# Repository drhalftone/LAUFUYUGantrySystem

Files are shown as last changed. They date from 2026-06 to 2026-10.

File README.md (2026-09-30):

# LAU FUYU Gantry System

Documentation, wiring reference, system diagram, and control software for a **FUYU
FMC4030 dual-X gantry** — two parallel X rails driven in hardware lockstep, with a Y
cross-beam riding between them, controlled from a PC over Ethernet.

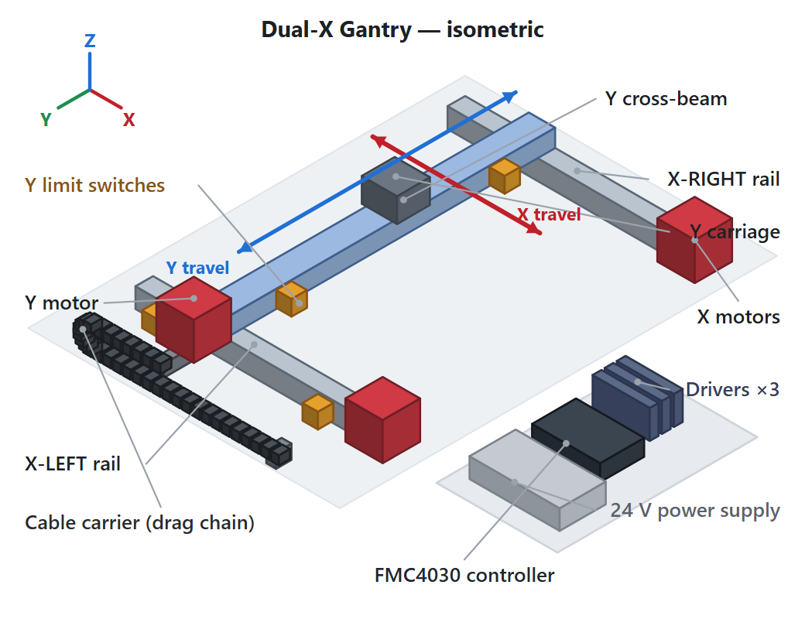
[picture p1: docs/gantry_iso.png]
Isometric diagram of the dual-X gantry


<sub>Isometric view of the system: the two X rails (driven in lockstep), the Y cross-beam
and carriage, the three motors, the photoelectric limit switches, the X-axis cable carrier (drag
chain), and the control cabinet (FMC4030 controller, three drivers, and 24 V supply).
Rendered from [`gantry_iso.svg`](gantry_iso.svg).</sub>

This repository contains three things:

| Path | What it is |
|---|---|
| [`FUYU_FMC4030_Assembly_Wiring_Manual.html`](FUYU_FMC4030_Assembly_Wiring_Manual.html) | Self-contained assembly & wiring manual (open in any browser). The authoritative reference for build, DIP-switch, and terminal-by-terminal wiring detail. |
| [`gantry_iso.svg`](gantry_iso.svg) | Isometric diagram of the mechanical system (embedded in the manual, also usable standalone). |
| [`FuyuRailController/`](FuyuRailController/) | Qt/C++ application that drives the gantry through the FMC4030 motion controller. |

> **Not redistributed here:** vendor-supplied FUYU datasheets, the FMC4030 SDK binaries,
> controller software, and reference archives. Building `FuyuRailController` against real
> hardware needs the FMC4030 SDK DLL from FUYU — see
> [`FuyuRailController/sdk/README.txt`](FuyuRailController/sdk/README.txt).

---

## 1. System overview

This is a **dual-X gantry**. Two parallel rails — **X-Left** and **X-Right** — run in the
same direction and move together; a **Y** cross-beam spans between them and travels along
their length.

The defining design choice is in how the X axis is driven:

- Each of the three motors keeps its **own** stepper driver, but the **two X drivers share
  one controller axis** (axis 1). They receive the *same* pulse and direction signals, so
  the two rails step in **perfect hardware lockstep** and physically cannot drift out of
  sync.
- The Y beam has its own axis (axis 3).
- Because the rails share a pulse source, the gantry **cannot be squared electronically** —
  squareness is set **mechanically at assembly** and held by the rigid beam.

The **FMC4030** is a pulse-type, 3-axis motion controller built around a 32-bit ARM chip.
It generates **pulse (PU)** and **direction (DR)** signals for three external stepper
drivers, reads the axis limit/home switches, provides 4 digital inputs and 4 digital
outputs, and is commanded by a host PC over **Ethernet** (default `192.168.0.30:8088`).

### Axis mapping

| Physical axis | Controller channel | Pulse / Dir / 5 V | Limit inputs |
|---|---|---|---|
| **X-Left** (gantry rail 1) | **Axis 1** (both X drivers share this axis) | `PU1 / DR1 / 5V` | `LP1 / LN1` |
| **X-Right** (gantry rail 2) | **Axis 1** (same terminals, paralleled) | `PU1 / DR1 / 5V` | none fitted |
| **Y** (cross-beam) | Axis 3 | `PU3 / DR3 / 5V` | `LP3 / LN3` |

Axis 2 (`PU2 / DR2`, `LP2 / LN2`) is **unused** — both X drivers are fed from axis 1.
This build uses **four** limit switches: a positive/negative pair on **X-Left** and a
positive/negative pair on **Y**.

---

## 2. Hardware

### 2.1 Bill of materials

| Qty | Item | Model / spec | Role |
|---|---|---|---|
| 1 | Motion controller | **FMC4030** (3-axis) | Pulse/dir generation, limit reading, host comms |
| 3 | Stepper driver | **FMDD50D40NOM** (DC 20–50 V, 1.0–4.0 A/phase) | One each: X-Left, X-Right, Y |
| 3 | Linear module (rail) | **FUYU FSK40** ball-screw module | X-Left, X-Right, and Y beam; carriage-top adapter plate in [`cad/`](cad/) |
| 3 | Stepper motor | **57HS056TF075A-03** (NEMA 23, 2-phase, 1.8°, 2.0 A, ≥ 80 N·cm) | X-Left rail, X-Right rail, Y beam |
| 4 | Limit / home switch | Slot-type photoelectric, **NPN normally-open (NO)**, 5–24 V | +/− pair on X-Left, +/− pair on Y (X-Right has none) |
| 1 | DC power supply | **24 VDC**, sized ≥ 3 × motor current + margin (24 V / 10 A is a safe start) | System power; AC 100–220 V input |
| 1 | Ethernet cable | Standard RJ45 | Host communication (CN3) |
| — | Wiring | Hook-up wire, ferrules, PE ground, AC fuse/breaker | Interconnect |

### 2.2 Component specifications

**Stepper motor — 57HS056TF075A-03**: 2-phase, 1.8° ±5%, 2.0 A/phase, 1.5 VDC, 0.75 Ω,
2.7 mH, holding torque ≥ 80 N·cm, NEMA 23 (57 mm) frame, Ø8 mm shaft, 4-wire (XH-4),
0.7 kg.

**Stepper driver — FMDD50D40NOM**: 2-phase DSP driver, DC 20–50 V input, 1.0–4.0 A/phase
(8 current steps), up to 40000 microsteps/rev, max pulse rate 200 Kpps, **falling-edge
active**, auto idle-current halving after pulses stop > 1.5 s, 118 × 24.3 × 75.5 mm.

**Limit / home switch**: slot-type photoelectric, 5–24 V, **NPN normally-open, low-level
active** (required by the FMC4030). Doubles as the **home/origin reference** for each axis.

**Controller — FMC4030**: 24 VDC power (VN+/VN−); 3 × 5 V pulse + direction outputs; 6
limit inputs (LP/LN × 3, 24 V NPN-NO); 4 digital inputs (24 V, low-active) and 4 digital
outputs (24 V open-drain, ≤ 300 mA); Ethernet (CN3), RS-232 DB9 (CN1), RS-232/485 RJ45
(CN2); default IP `192.168.0.30`, port `8088`.

### 2.3 Driver DIP-switch setup

Set the 8 DIP switches on **each** FMDD50D40NOM driver *before* wiring power.

- **SW4 = OFF** — selects pulse/subdivision mode. **Required.** `SW4 = ON` puts the driver
  in I/O mode and it will ignore the FMC4030's pulses.
- **Output current (SW1–SW3) → 2.0 A** to match the motor: `SW1 = OFF · SW2 = OFF · SW3 = ON`.
- **Microstepping (SW5–SW8) → 1600 steps/rev** (recommended start):
  `SW5 = OFF · SW6 = OFF · SW7 = ON · SW8 = ON`.

Use the **same** microstep value on all three drivers and record it — distance/speed math
depends on steps-per-rev.

### 2.4 Wiring summary

Full, terminal-by-terminal wiring (with diagrams and the complete terminal reference) is in
the **HTML manual**, §7–§12. Summary:

**Power (§7):** build a 24 V bus from the supply; feed the controller (VN+/VN−), all three
drivers (V+/V−), and the limit switches from it. Mains (100–220 VAC) goes only to the
supply's L / N / earth.

**Motor → driver (§8)** — 57HS XH-4 colours map straight to coils. Coil pairing is what
matters: **A = Black + Green, B = Red + Blue**.

| Motor pin | Colour | Coil | Driver |
|---|---|---|---|
| 1 | Black | A+ | `A+` |
| 2 | Green | A− | `A−` |
| 3 | Red | B+ | `B+` |
| 4 | Blue | B− | `B−` |

Both X motors are mounted the **same way** and wired with the **same** colour map (no
`A+/A−` swap) so the shared rotation moves both carriages the same direction. X direction
is fixed **in wiring** (it can't be inverted in software because the rails share one axis);
Y direction can be inverted in wiring *or* software.

**Driver → controller (§9)** — **common-anode**: the controller's 5 V drives each driver's
`PU+`/`DR+` (tied together); the controller's `PUx`/`DRx` pins sink into `PU−`/`DR−`. The
**two X drivers are paralleled onto axis 1** (`5V`, `PU1`, `DR1`); the Y driver uses axis 3
(`5V`, `PU3`, `DR3`). Leave `MF+/MF−` open (holding torque on). Use the **5 V** rail for
`PU+/DR+`, never 24 V.

**Limit switches (§10)** — each switch: **Brown → 24 V+, Blue → 0 V, Black → signal**.
Positive-end switch black wire → `LP`, negative-end → `LN`. X gantry pair → `LP1 / LN1`
(axis 1); Y pair → `LP3 / LN3`. Switches **must be NPN normally-open** (inputs are
low-level active).

**Digital I/O & comms (§11):** 4 inputs `IN0–IN3` (24 V active-low); 4 open-drain outputs
`OP1–OP4` (sink ≤ 300 mA, wire load between 24 V+ and the output). Host link is Ethernet on
**CN3**; set the PC adapter to the controller's subnet (e.g. `192.168.0.35 / 255.255.255.0`)
and verify with `ping 192.168.0.30`.

### 2.5 Mechanical & safety notes

- **Square the gantry mechanically:** set the two X rails truly parallel and equal-length,
  mount the Y beam perpendicular (equal diagonals), and start both X carriages at the same
  position before fixing the beam. The controller can't correct rail-to-rail squareness.
- **Mount both X motors identically** (same orientation, same end) so shared rotation =
  same travel. The §14 jog test confirms it: nudge axis 1 — both rails should move together.
- Position the **negative-end** switch at the home/zero end and the **positive-end** switch
  at the far end of each axis, with margin before the hard stop. X-Right has no over-travel
  switch, so set conservative soft-travel limits in software.
- Keep ≥ 50 mm between side-by-side drivers (thermal shutdown at 80 °C); keep AC mains wiring
  separated from low-voltage signal/Ethernet wiring.
- ⚠ **The supply primary side carries 100–220 VAC.** Wire everything de-energized with the
  AC plug removed; bond the controller `PE` and frame to protective earth; don't plug/unplug
  a motor while its driver is powered.

---

## 3. Software — `FuyuRailController`

A small **Qt Widgets** application for driving the FMC4030. Its defining choice: it
**reuses the Velmex widget classes** from `LAU3DVideoRecorder` *verbatim* and only **swaps
the controller** — `LAUVelmexController` is reimplemented to talk to the FMC4030 over
Ethernet instead of a serial Velmex VXM. You get the proven Velmex control panel driven by
FUYU hardware.

### 3.1 Build & run

Verified to build clean with **Qt 6.9.3, MSVC 2022 (64-bit)**.

**Simulation (default — no hardware or SDK needed):**

```sh
qmake
nmake            # Windows/MSVC   (or make / jom)
./FuyuRailController
```

A built-in simulator eases each axis toward its commanded target and emulates the limit
switches, so the entire UI is exercisable with nothing plugged in. In Qt Creator: open
`FuyuRailController.pro`, pick the Qt 6 / MSVC 2022 kit, Build & Run.

**Real hardware:**

```sh
qmake CONFIG+=hardware
nmake
```

The vendor library is loaded **at run time** via `QLibrary`, so the build needs **no `.lib`
and no `.h`** — and it launches even with no SDK present (reporting *disconnected*). Place
`FMC4030-Dll.dll` (Windows, 64-bit) next to the `.exe` or on `PATH`, or `libFMC4030-Lib.so`
on the Linux library path; bitness must match the build. The `.pro` auto-copies
`sdk/FMC4030-Dll.dll` next to the built executable on Windows.

The controller defaults to **`192.168.0.30:8088`**; put your PC adapter on the same subnet.

### 3.2 Axis mapping in software

The FMC4030 SDK numbers axes `0 = X (PU1)`, `1 = Y (PU2)`, `2 = Z (PU3)`. On this gantry the
shared-X / separate-Y layout maps as:

| App axis | SDK index | Physical |
|---|---|---|
| X gantry | 0 | both X rails (shared signal) |
| (unused) | 1 | — |
| Y beam | 2 | cross-beam carriage |

`main.cpp` builds the panel with `LAUMultiVelmexWidget({0, 2})` — one checkable group box
per axis, each with Left-Limit / Slider-Position / Right-Limit rows and Calibrate / Center /
Scan buttons, plus a `?` settings dialog.

### 3.3 How it works

- **Units:** the widgets speak integer "counts"; here **1 count = 1 µm** (0.001 mm). The
  controller converts counts ↔ millimetres at the SDK boundary; the display shows **mm**
  (default) or **inches**, switchable in the `?` dialog (the **Speed** field follows the
  unit). The unit choice is shared by all axes.
- **Motion is non-blocking.** A move issues `FMC4030_Jog_Single_Axis` once; a 500 ms timer
  polls `FMC4030_Check_Axis_Is_Stop` until the axis settles, so position stays live and a
  Stop can be processed mid-move. The position slider is a *setpoint* (Center/Scan jump
  straight to it).
- **Calibration discovers travel from the limit switches**, like Velmex: `calibrateLeft()`
  homes the negative switch (sets zero); `calibrateRight()` seeks the positive switch (sets
  travel, bounded to a 2000 mm safety ceiling if a switch is missing). The slider range then
  reflects real travel.
- **Settings dialog (`?`):** Units · Home Toward · Speed · Scan Steps. The Velmex-specific
  mechanical fields were removed because the FMC4030 abstracts them away.

### 3.4 Blocking vs non-blocking SDK (important)

FUYU ships **two** builds of the DLL — *blocking* and *non-blocking* — with identical
function names but different behaviour. **This project requires the non-blocking X64 build**,
because the controller is poll-based (one jog, then poll is-stopped). With the blocking DLL,
a motion call doesn't return until the move finishes — you lose live position feedback and
the ability to abort mid-move, which is a safety concern on a gantry. See
[`FuyuRailController/sdk/README.txt`](FuyuRailController/sdk/README.txt).

### 3.5 Source layout

| File | Purpose |
|---|---|
| `lauvelmexwidget.h` / `.cpp` | Velmex widget classes (verbatim) **+** the FMC4030-backed `LAUVelmexController` and trimmed `LAUVelmexSettingsDialog` |
| `main.cpp` | Builds `LAUMultiVelmexWidget({0, 2})` |
| `FuyuRailController.pro` | qmake project; selects simulation vs hardware |
| `sdk/` | Holds the non-blocking X64 `FMC4030-Dll.dll` (not committed) + `README.txt` |

---

## 4. Repository layout

```
.
├── FUYU_FMC4030_Assembly_Wiring_Manual.html   # assembly & wiring manual
├── gantry_iso.svg                             # isometric system diagram
├── README.md                                  # this file
└── FuyuRailController/                         # Qt/C++ controller app
    ├── FuyuRailController.pro
    ├── main.cpp
    ├── lauvelmexwidget.h / .cpp
    └── sdk/README.txt
```

---

## 5. Credits & license

© 2026 Dr. Daniel L. Lau. The control application reuses the `LAU3DVideoRecorder` Velmex
module. FUYU, FMC4030, and the component model numbers are trademarks/products of their
respective owners; their proprietary datasheets and SDK binaries are not redistributed here.

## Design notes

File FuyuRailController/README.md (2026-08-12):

# FuyuRailController

A small Qt Widgets application for driving the **FUYU FMC4030** three-axis motion
controller that runs the dual-X gantry (two X rails + a Y cross-beam).

Its defining design choice: it **reuses the Velmex widget classes** from
`LAU3DVideoRecorder` *verbatim* and only **swaps the controller**. The Velmex GUI
(`LAUVelmexWidget`, `LAUMultiVelmexWidget`, `LAUVelmexSettingsDialog`, `LAUDoubleSpinBox`)
is unchanged; `LAUVelmexController` is reimplemented to talk to the FMC4030 over Ethernet
instead of a serial VXM. So you get the proven Velmex control panel, driven by FUYU hardware.

---

## Quick start (simulation — no hardware or SDK needed)

The default build runs against a built-in **software simulator**, so it compiles and runs
with nothing plugged in.

**Qt Creator:** open `FuyuRailController.pro`, select the Qt 6 / MSVC 2022 kit, and Build &
Run.

**Command line:**
```
qmake
nmake            # (Windows/MSVC)   or  make / jom
./FuyuRailController
```

Verified to build clean with **Qt 6.9.3, MSVC 2022 (64-bit)**.

You'll see one checkable group box per axis ("X gantry Controls:", "Y beam Controls:"),
each with Left-Limit / Slider-Position / Right-Limit rows and Calibrate / Center / Scan
buttons, plus a `?` settings dialog. In simulation each axis eases toward its commanded
target and the limit switches are emulated, so you can exercise the whole UI.

## Building for real hardware

The vendor library is loaded **at run time** (via `QLibrary`), so the build needs **no
`.lib` and no `.h`** — only the DLL at run time, and only if you actually have hardware.

1. Build with the `hardware` config:
   ```
   qmake CONFIG+=hardware
   nmake
   ```
   In Qt Creator: **Projects ▸ Build ▸ qmake ▸ Additional arguments → `CONFIG+=hardware`**.
   (This build links and runs even with **no** SDK present — it just reports *disconnected*.)
2. For real hardware, place the runtime library where it can be found:
   - Windows: **`FMC4030-Dll.dll`** next to the built `.exe` (or on the `PATH`)
   - Linux: **`libFMC4030-Lib.so`** on the library path
3. **Bitness must match** (use the 64-bit DLL with the MSVC 64-bit kit). On startup the app
   resolves the SDK symbols; if the DLL is missing or a symbol is absent it logs a warning
   and runs disconnected.

A copy of the DLL already lives in `sdk/` and is auto-copied next to the built `.exe` by the
`.pro` (win32 post-link step), so a hardware build finds it with no manual copying.

### Blocking vs non-blocking SDK (important)

FUYU ships **two** builds of the DLL — *blocking* and *non-blocking* — with identical function
names but different behaviour. **This project uses the non-blocking X64 build** (`sdk/FMC4030-Dll.dll`,
extracted from `国外FMC4030/FMC4030 API file (non blocking).rar`).

It must stay non-blocking, because `LAUVelmexController` is **poll-based**: it issues one
`FMC4030_Jog_Single_Axis` and then polls `FMC4030_Check_Axis_Is_Stop` from a 500 ms timer.

| | Non-blocking (used) | Blocking (do **not** use) |
|---|---|---|
| motion call returns | immediately | only when the move finishes |
| live position during a move | yes — the poll updates it | no — jumps at the end |
| Stop / abort mid-move | works | can't be processed until the move ends |
| controller thread during a move | responsive | frozen inside the call |

With the blocking build the code still *compiles and connects*, and simple point-to-point moves
complete — so it can look fine in casual testing — but you lose live position feedback and the
ability to abort a move, which is a safety concern on a gantry. If you ever re-extract the DLL,
take it from the **"non blocking"** archive (X64 subfolder). See `sdk/README.txt` for the path.

### Network setup

The controller defaults to `192.168.0.30:8088`. Set the PC adapter that's cabled to it to a
static address on the **same subnet** — e.g. `192.168.0.35 / 255.255.255.0` — and leave the
**default gateway blank**: the controller sits on an isolated segment, and a gateway here
would compete with the default route of whatever adapter carries your internet.

**1. Find the right adapter.** The FMC4030 is a 10/100 device, so its port shows up at
100 Mbps:

```powershell
Get-NetAdapter | Select-Object Name,ifIndex,Status,LinkSpeed
Get-NetIPConfiguration | Select-Object InterfaceAlias,IPv4Address,IPv4DefaultGateway
```

An address of **`169.254.x.x`** on that port is the classic symptom: DHCP is on (or is off with
no static address set), nothing answered, and Windows self-assigned an APIPA address. It cannot
reach `192.168.0.0/24` in that state.

**2. Set the static address** (needs an elevated prompt; substitute your adapter name):

```powershell
netsh interface ip set address name="Ethernet 2" static 192.168.0.35 255.255.255.0
```

**3. Verify** — both checks should pass before launching the app:

```powershell
ping 192.168.0.30
Test-NetConnection -ComputerName 192.168.0.30 -Port 8088   # TcpTestSucceeded : True
```

`TcpTestSucceeded` is the one that matters — it proves the SDK's port is open. Note that
`Test-NetConnection` may report `PingSucceeded : False` even when plain `ping` gets replies;
that's its own ICMP path being filtered, not a controller fault.

To undo, put the adapter back on DHCP: `netsh interface ip set address name="Ethernet 2" dhcp`.

The app **remembers the last IP/port** in `QSettings`, so the `192.168.0.30` default only
applies on a first run — if a stale address was saved, correct it in the `?` dialog.

---

## Axis mapping

The FMC4030 SDK numbers axes `0 = X (PU1)`, `1 = Y (PU2)`, `2 = Z (PU3)`. On this gantry both
X rails share **one** controller axis (a single PU/DR signal), so:

| App axis | SDK index | Physical |
|---|---|---|
| X gantry | 0 | both X rails (shared signal) |
| (unused) | 1 | — |
| Y beam | 2 | cross-beam carriage |

`main.cpp` creates the panel with `LAUMultiVelmexWidget({0, 2})`.

## How it works

- **Units:** the widgets speak integer "counts"; here **1 count = 1 µm** (0.001 mm). The
  controller converts counts ↔ millimetres at the SDK boundary, and the display can show
  **mm** (default) or **inches** — switchable in the `?` dialog, where the **Speed** field
  also follows the unit (mm/s ↔ in/s). The unit choice is shared by every axis.
- **Motion is non-blocking.** A move issues `FMC4030_Jog_Single_Axis` once; the controller's
  500 ms `timerEvent` polls `FMC4030_Check_Axis_Is_Stop` until the axis settles. The position
  slider is a *setpoint* (Center/Scan jump straight to it — no scrolling). This depends on the
  **non-blocking** SDK build (see *Blocking vs non-blocking SDK* above).
- **Calibration discovers travel from the limit switches**, like Velmex: `calibrateLeft()`
  homes the **negative** switch (sets zero) and `calibrateRight()` seeks the **positive**
  switch (sets the travel). The sliders' range then reflects the real travel — there is no
  manual "full travel" field.
- **Settings dialog** (`?`): **Units · Home Toward · Speed · Scan Steps**. The Velmex-specific
  mechanical fields (rotary, motor clicks/rotation, travel/rotation) were removed because the
  FMC4030 abstracts them away.

## Files

| File | Purpose |
|---|---|
| `lauvelmexwidget.h/.cpp` | Velmex widget classes (verbatim) **+** the FMC4030-backed `LAUVelmexController` and trimmed `LAUVelmexSettingsDialog` |
| `main.cpp` | Builds `LAUMultiVelmexWidget({0, 2})` |
| `FuyuRailController.pro` | qmake project; selects simulation vs hardware |
| `sdk/` | holds the **non-blocking X64** `FMC4030-Dll.dll` (auto-copied next to the `.exe`); see `sdk/README.txt` |

## FMC4030 vs Velmex (short version)

The Velmex VXM is an RS-232 controller you drive with ASCII commands in motor **step counts**,
with **blocking** moves (poll busy/ready). The FMC4030 is an **Ethernet** controller driven by
a C **SDK** in native **millimetres**, with **non-blocking** moves (poll is-stopped) and
hardware multi-axis interpolation. We kept `LAUVelmexController`'s public interface identical
and replaced only its internals (serial+steps → SDK+mm), so the GUI didn't change.

## Things to verify on the bench

- `calibrateRight` relies on the FMC4030 **halting the axis at the positive limit switch**
  (bounded to a 2000 mm safety ceiling if a switch is missing). Confirm the controller stops
  at `LP` before trusting auto-travel.
- Homing is assumed to **zero the axis at the switch** — standard for the FMC4030 but confirm.
- `FMC4030_Set_Output` polarity follows the SDK wording (status `0` = output HIGH); flip in the
  controller if your wiring is inverted.

---

© 2026 Dr. Daniel L. Lau. Reuses the LAU3DVideoRecorder Velmex module.

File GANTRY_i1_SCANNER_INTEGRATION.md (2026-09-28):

# Replacing the i1 iSis with a FUYU Gantry + i1Pro — Integration Design

**Status:** design sketch only (no code yet).
**Goal:** retire the sealed **i1 iSis** chart scanner and rebuild the same
chart-measurement workflow from two off-the-shelf pieces we already control:

- the **FUYU FMC4030 dual-X gantry** (`FUYUAutomation/FuyuRailController`) for **motion**, and
- the **X-Rite i1Pro** spectrophotometer (`LAUXRiteController`, SDK 4.2.9) for **measurement**.

The iSis combines motion and measurement in one box. We split those: the gantry
positions the i1Pro over each patch, and a thin orchestrator triggers a spot
measurement at every stop. Everything downstream of acquisition is reused
unchanged.

---

## 1. Why this is mostly glue, not a rewrite

### 1.1 The data structures already match

The i1Pro SDK and the iSis SDK share identical measurement primitives:

| Quantity | iSis | i1Pro |
|---|---|---|
| Spectral bands | `SPECTRUM_SIZE == 36` (380–730 nm @ 10 nm) | same |
| Tristimulus | `TRISTIMULUS_SIZE == 3` | same |
| Density | `DENSITY_SIZE == 4` | same |
| Trigger | `ISIS_TriggerMeasurement(...)` | `I1_TriggerMeasurement(dev)` |
| Read back | `ISIS_GetSpectrum/GetTriStimulus/GetDensities(buf, row, col)` | `I1_GetSpectrum/GetTriStimulus/GetDensities(dev, buf, index)` |

Because the shapes are identical, **`LAUi1IsisDialog::ColorMeasurement` is reused
verbatim**, and so are:

- `generateTestPattern()` — TIFF chart rendering,
- `saveMeasurementsToDisk()` / `readMeasurementsFromDisk()` — CSV,
- `exportToI1ProfilerCGATS()` and `exportToCxF3()`,
- `mergeMeasurementLists()`, `writeTI3File()`, and the Argyll `targen`/`colprof` flow.

We replace **only** the acquisition path (`scanTarget()`), not the data model or
the outputs.

### 1.2 The gantry already exposes the exact hook we need

`LAUMultiVelmexWidget::scanUserPath(QList<QVector4D> points)` accepts an arbitrary
list of coordinates, rasters through them non-blocking, and emits

```
emitTriggerScanner(float pos, int n, int N)   // n = current point, N = total
```

**at each point.** That signal is precisely where the i1Pro measurement fires. We
do not have to write the motion loop — it exists and is already poll-settled
(`FMC4030_Jog_Single_Axis` then poll `FMC4030_Check_Axis_Is_Stop` on a 500 ms
timer). The gantry is built with axes `{0, 2}` = **X gantry + Y beam**, which is
the 2-D plane we need.

### 1.3 The i1Pro measurement logic already exists

`LAUEyeOneDialog` (in `LAUXRiteController`) already wraps the i1Pro lifecycle:
`I1_GetDevices` → `I1_OpenDevice` → mode select (`I1_REFLECTANCE_SPOT`) →
`I1_Calibrate` → `I1_TriggerMeasurement` → `I1_GetSpectrum`. That code refactors
directly into a reusable, headless **measurement helper** (no dialog UI required).

---

## 2. The conceptual mapping

| iSis (today) | Gantry + i1Pro (proposed) |
|---|---|
| `scanTarget()` sets chart geometry in mm, waits for chart insert, pre-scans to register | Jog to two corners to register the chart, generate an XY path from the patch grid, hand it to `scanUserPath()` |
| `ISIS_TriggerMeasurement(false)` — 2 rows per trigger | `emitTriggerScanner` callback → one `I1_TriggerMeasurement` per patch |
| `ISIS_GetTriStimulus/Spectrum/Densities(row, col)` | `I1_Get*(device, buf, 0)` into the same `ColorMeasurement` |
| optical auto-registration via the alignment bar | **two-corner manual jog** (see §4) |
| device finds patches itself | host computes patch centres → gantry XY (mm) |

---

## 3. Proposed architecture

Recommended: a **new combined dialog**, e.g. `LAUGantryScannerDialog`, that leaves
the existing iSis path untouched and owns three collaborators:

```
LAUGantryScannerDialog
├── motion:       LAUMultiVelmexWidget({0, 2})      // reused from FuyuRailController
│                 (or just its LAUVelmexController)
├── measurement:  LAUi1ProMeasurer                  // headless helper refactored
│                 (open / calibrate / measure)       //   out of LAUEyeOneDialog
└── data + I/O:   LAUi1IsisDialog::ColorMeasurement  // reused verbatim,
                  + generateTestPattern / exporters  //   incl. all exports
```

The scan loop **replaces** `scanTarget()`:

```
1. Operator registers the chart (two-corner jog, §4).
2. Build QList<QVector4D> path = patchCentresToXY(grid, corners)   // §4.3
3. controller->scanUserPath(path)
4. On each emitTriggerScanner(pos, n, N):
     - confirm axes stopped + dwell (§5.2)
     - measurer.trigger(); measurer.readInto(measurement[n])
     - measurement[n].row/col = gridIndexOf(n)
     - append to scanMeasurements
5. On completion: hand scanMeasurements to the existing exporters.
```

Alternative structures considered (not recommended for the first cut):

- **Swap inside `LAUi1IsisDialog::scanTarget()`** — least new UI, but deletes the
  iSis option and entangles two device stacks in one method.
- **Merge the repos** — pull the Velmex classes into `LAUXRiteController`. Worth
  doing eventually so it is one app/one build, but it is a packaging decision that
  can follow a working prototype.

> Either way the two repos must be brought into one build. The Velmex classes
> (`lauvelmexwidget.h/.cpp`) and the i1Pro SDK linkage (`i1Pro64.lib`, runtime
> `FMC4030-Dll.dll`) both end up in the same `.pro`.

---

## 4. Registration — the two-corner jog

The gantry has no idea where the printed chart sits on its bed; unlike the iSis it
cannot find the chart optically. So the operator **jogs the i1Pro head to two
diagonally-opposite patch centres** and we derive the patch→XY map from those.

### 4.1 Procedure

1. Place and fix the chart on the bed (a registration corner/fence helps
   repeatability but is not required).
2. Calibrate the i1Pro on its white tile (§5.1).
3. Jog the head until the aperture is centred on patch **(row 0, col 0)** →
   record gantry position **P₀ = (x₀, y₀)** in mm.
4. Jog to the opposite corner patch **(row R−1, col C−1)** (for the default chart,
   row 29, col 28) → record **P₁ = (x₁, y₁)**.
5. Store P₀, P₁ for the run (and persist to `QSettings` for repeat runs on the
   same fixture).

The jog UI already exists: the Velmex position sliders / spin boxes move a single
axis to a setpoint. A small "Set corner 1 / Set corner 2" pair of buttons captures
the current `position(0)` / `position(2)` of each axis.

### 4.2 What two corners give you (and what they do not)

Two diagonally-opposite patch centres pin down **translation + independent
per-axis scale** under the assumption that the chart's rows/cols are
**axis-aligned** with the gantry (no in-plane rotation or skew):

```
colPitchX = (x₁ − x₀) / (C − 1)      // mm of X per column step
rowPitchY = (y₁ − y₀) / (R − 1)      // mm of Y per row step
originXY  = P₀                        // centre of patch (0,0)
```

This absorbs print scaling and bed placement automatically — we do **not**
hard-code the 6 mm patch pitch; we measure it from the two corners. (The iSis
artwork is ~6 mm patches over a 204 mm sheet, a useful sanity check: expect
`colPitchX ≈ rowPitchY ≈ 6 mm`.)

**Limitation:** two diagonal points cannot separate rotation from scale (3 unknowns,
2 equations). If the chart is slightly **rotated** on the bed, a diagonal pair
silently folds that rotation into the pitches and mis-targets interior patches.

Two robust options, both still "two corners":

- **Same-edge pair (handles rotation):** jog to **(0,0)** and **(0, C−1)** — both on
  the top row. Their difference is the pure **column axis vector** `u`, which gives
  column pitch **and** the chart's rotation angle. Take the row axis `v` ⟂ `u`
  (perpendicular), with row pitch from the artwork or a quick third tap. Best when
  the bed fixture cannot guarantee alignment.
- **Diagonal pair (simplest):** jog to **(0,0)** and **(R−1, C−1)**, assume
  axis-aligned. Fine when a fence/corner squares the chart to the gantry travel.

Recommendation: **diagonal pair + a mechanical fence** for the first build (assume
no rotation); upgrade to the same-edge pair (or a third corner → full affine) only
if bench tests show interior-patch drift.

### 4.3 Patch → XY (axis-aligned, diagonal corners)

```cpp
// grid index n (raster order) → patch (row, col) → gantry XY in mm
int row = n / C;
int col = n % C;
double x = originX + col * colPitchX;     // colPitchX = (x1-x0)/(C-1)
double y = originY + row * rowPitchY;     // rowPitchY = (y1-y0)/(R-1)
path << QVector4D(x, 0.0f, y, 0.0f);      // dim 0 = X, dim 2 = Y (Z,W unused)
```

`scanUserPath()` already clamps each coordinate to the calibrated axis travel, so a
bad corner capture cannot drive the head past a soft limit.

> **Full-affine upgrade (optional):** capturing a **third** corner (e.g. (R−1, 0))
> lets you solve a general 2-D affine map `XY = A·[col,row] + b` (handles rotation
> **and** skew). Same UI, one more "Set corner 3" tap. Worth keeping the math
> general so this is a config flag, not a rewrite.

---

## 5. Engineering concerns (the parts that are not glue)

### 5.1 No Z axis — fixed standoff
The gantry is X/Y only (`{0, 2}`); there is no Z. The i1Pro is a **contact spot**
instrument whose aperture wants to sit on the media. So the head mounts to the Y
carriage at a **fixed Z**, and reflectance accuracy depends on the media being
**flat and at a known height**. This is the largest physical risk. Mitigations:
spring-loaded/compliant head mount, a vacuum or platen to hold media flat,
verification against a known reference chart. (If standoff proves critical, a
future Z stage on the unused FMC4030 axis 1 is an option — but that axis currently
carries the shared X signal, so it would need rewiring.)

### 5.2 Settling dwell
Motion is non-blocking and "settled" means `FMC4030_Check_Axis_Is_Stop` returned
stopped. Add a short **dwell** (e.g. 200–500 ms, tunable) after stop and before
`I1_TriggerMeasurement` so carriage vibration does not smear the reading.

### 5.3 Calibration & expiry
The i1Pro must be **calibrated on its white tile** before a run, and calibration
expires (`I1_TIME_SINCE_LAST_CALIBRATION` is −1 / aged). Two patterns:

- **Manual:** operator calibrates by hand (head on tile) before the run, like
  `LAUEyeOneDialog::onCalibrateButtonClicked()`.
- **Automated:** mount the white tile at a **known XY** on the bed; the scan loop
  parks there and calls `I1_Calibrate()` at the start (and optionally every N
  patches if a long run risks expiry).

### 5.4 Throughput
~870 patches × (move + dwell + ~1–2 s measurement) ≈ **15–30 min** per chart,
versus seconds for the iSis. Acceptable, but set expectations and show a progress
dialog (the iSis path already used `QProgressDialog`).

### 5.5 Threading
`LAUVelmexController` lives in its own `QThread` and polls on a 500 ms timer. The
i1Pro SDK calls must be serialized against motion. Cleanest first cut: drive the
measurement from the **GUI thread** inside the `emitTriggerScanner` slot
(`Qt::QueuedConnection`), only after motion confirms stopped — no shared-state race
with the controller thread.

### 5.6 M0 / M1 / M2 (UV handling)
The iSis exposed an illumination mode (UV / No-UV). The i1Pro2 supports M0/M1/M2 via
`I1_RESULT_INDEX_KEY` on a dual measurement (subject to device variant — UV-cut
units expose only M2). Map the old UV toggle onto the i1Pro result index where the
hardware allows; otherwise drop to a single mode and note it in the export header
(`MEASUREMENT_MODE`).

### 5.7 Registration drift over a run
Thermal/mechanical drift over a 20-minute run can shift the origin. If bench tests
show it, re-tap a corner mid-run or add fiducials. Out of scope for v1.

---

## 6. File / change checklist (no code yet)

| Item | Action |
|---|---|
| `lauvelmexwidget.h/.cpp` | **Reuse** as the motion layer (verbatim from `FuyuRailController`). |
| i1Pro measurement helper | **New** `LAUi1ProMeasurer` — refactor open/calibrate/measure out of `LAUEyeOneDialog` (no UI). |
| `LAUGantryScannerDialog` | **New** orchestrator: registration UI (two-corner jog), path build, scan loop, progress. |
| `ColorMeasurement` + exporters | **Reuse** from `LAUi1IsisDialog` (CSV / CGATS / CxF3 / TIFF / Argyll). Consider lifting them into a shared header so the new dialog does not depend on the iSis dialog. |
| `patchCentresToXY()` | **New** small geometry function (§4.3); keep it affine-general so 2- or 3-corner is a flag. |
| Build (`.pro`) | **Merge** Velmex sources + i1Pro SDK link (`i1Pro64.lib`) + runtime `FMC4030-Dll.dll` copy step into one project. Keep the FMC4030 **non-blocking** DLL (poll-based control depends on it). |
| `main.cpp` | Add an entry path that launches `LAUGantryScannerDialog` (alongside, or instead of, the iSis dialog). |

---

## 7. Open questions to resolve before implementation

1. **Head mount & standoff:** how is the i1Pro fixtured to the Y carriage, and how
   is flat media / fixed height guaranteed? (Drives §5.1 — the main risk.)
2. **Calibration tile:** manual pre-run, or mounted at a known XY for automated
   calibration? (§5.3)
3. **Chart squareness:** is there a fence/corner to square the chart to gantry
   travel? Decides diagonal-pair vs same-edge-pair vs full-affine registration (§4).
4. **UV/OBA need:** is M1/M2 required, or is single-mode M0 acceptable? (§5.6)
5. **Packaging:** one merged app, or keep `FuyuRailController` and
   `LAUXRiteController` separate and share code via a small static lib?

---

© 2026 Dr. Daniel L. Lau. Design note; references `LAUXRiteController`
(i1 iSis / i1Pro controller) and `FUYUAutomation/FuyuRailController` (FMC4030 gantry).

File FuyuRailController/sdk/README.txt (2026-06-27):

FMC4030 SDK -- runtime DLL loading
==================================

The app loads the FMC4030 vendor library at RUN TIME (via QLibrary), so the build needs
no .lib and no .h, and has no link-time dependency on the SDK.  A "hardware" build even
launches when the DLL is absent -- it just reports "disconnected".

CURRENT DLL: FMC4030-Dll.dll is the NON-BLOCKING, 64-bit (X64) build, extracted from:
    ../../国外FMC4030/FMC4030 API file (non blocking).rar
        -> FMC4030二次开发库文件（非阻塞）/FMC4030-DLL-X64-20240920/FMC4030-Dll.dll

The non-blocking build is REQUIRED: LAUVelmexController issues one motion command and then
polls FMC4030_Check_Axis_Is_Stop from a 500 ms timer.  With the *blocking* build the motion
call would not return until the move finished, freezing the controller thread (no live
position, and Stop/abort could not be processed mid-move).  Do not swap in the blocking DLL.

This file is auto-copied next to the built .exe by the .pro (win32 post-link step).  For a
manual deploy, place FMC4030-Dll.dll next to FuyuRailController.exe (or on the PATH).

Bitness must match the build (use this 64-bit DLL with the 64-bit MSVC kit).  The app
resolves these symbols at startup:
    FMC4030_Open_Device, FMC4030_Close_Device, FMC4030_Jog_Single_Axis,
    FMC4030_Check_Axis_Is_Stop, FMC4030_Home_Single_Axis, FMC4030_Stop_Single_Axis,
    FMC4030_Get_Axis_Current_Pos
If any is missing it logs a warning and runs disconnected.

NOTE: the simulation build needs none of these files.

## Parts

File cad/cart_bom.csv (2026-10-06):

Unit | Section | Part | Qty | Description | Unit $ | Ext $
Bench box | Frame | 1010 | 2 | Top front/back rail, 24 in | 10.8 | 21.6
Bench box | Frame | 1010 | 2 | Top side rail, 22 in | 9.9 | 19.8
Bench box | Frame | 1010 | 4 | Shelf rail, 20 in | 9.0 | 36.0
Bench box | Frame | 1010 | 1 | Camera mast, 45.71 in | 20.57 | 20.57
Bench box | Frame | 1010 | 1 | Camera boom, 13 in | 5.85 | 5.85
Bench box | Frame | 1010-cut | 10 | 1010 cut charge, per cut | 3.0 | 30.0
Bench box | Frame | 2020 | 4 | Post, 4.71 in | 5.32 | 21.29
Bench box | Frame | 2020-cut | 4 | 2020 cut charge, per cut | 3.18 | 12.72
Bench box | Joining | 4132 | 26 | 10 series 2-hole gusseted inside corner bracket | 7.11 | 184.86
Bench box | Joining | 3416 | 52 | Bolt assembly: 1/4-20 x .375 BHSCS + economy T-nut, 2 per 4132 | 0.71 | 36.92
Bench box | Surfaces | 2637 | 1 | Shelf panel (notch the 4 post corners 2 x 2 in), 24 x 24 in, Lite ACM .236 black | 55.32 | 55.32
Bench box | Surfaces | 2637-cut | 1 | Panel cut-to-size charge, per panel | 16.13 | 16.13
Bench box | Surfaces | 3321 | 4 | Bolt assembly: 1/4-20 x .5 FBHSCS + economy T-nut, panel to rail (countersink the panel) | 0.87 | 3.48
Bench box | Camera | ballhead | 1 | 1/4-20 mini ball head for the camera (est.) | 15.0 | 15.0
Bench box | Camera | 3393-cam | 1 | 1/4-20 stud + economy T-nut, ball head to boom (est.) | 0.73 | 0.73
Bench box | Finish | 2015 | 4 | 10 series 1 x 1 end cap (exposed 1010 ends) | 2.02 | 8.08
Wheeled cart | Frame | 1010 | 2 | Top front/back rail (cantilevers to laptop table), 38 in | 17.1 | 34.2
Wheeled cart | Frame | 1010 | 3 | Top side + laptop end rail, 22 in | 9.9 | 29.7
Wheeled cart | Frame | 1010 | 4 | Lower ring rail, 20 in | 9.0 | 36.0
Wheeled cart | Frame | 1010-cut | 9 | 1010 cut charge, per cut | 3.0 | 27.0
Wheeled cart | Frame | 2020 | 4 | Leg, 16.07 in | 18.16 | 72.64
Wheeled cart | Frame | 2020-cut | 4 | 2020 cut charge, per cut | 3.18 | 12.72
Wheeled cart | Joining | 4132 | 22 | 10 series 2-hole gusseted inside corner bracket | 7.11 | 156.42
Wheeled cart | Joining | 3416 | 44 | Bolt assembly: 1/4-20 x .375 BHSCS + economy T-nut, 2 per 4132 | 0.71 | 31.24
Wheeled cart | Locating | angle | 4 | Aluminium angle 2 x 2 x 1/8 in, cut 3.5 in, 3 holes (est.) - box locators on the leg tops | 6.0 | 24.0
Wheeled cart | Locating | 3416 | 12 | Bolt assembly: 1/4-20 x .375 BHSCS + economy T-nut, locator angles (1/32 in shim behind each flange) | 0.71 | 8.52
Wheeled cart | Mobility | 2323 | 4 | Flange mount swivel caster, 5 in, top brake, 300 lb | 42.78 | 171.12
Wheeled cart | Mobility | 2419 | 4 | 10 series flange mount caster base plate | 28.46 | 113.84
Wheeled cart | Mobility | SHCS-5/16 | 16 | 5/16-18 x 5/8 SHCS, caster flange to 2419 plate (est.) | 0.35 | 5.6
Wheeled cart | Mobility | leg-end | 8 | Tap 2020 end hole 1/4-20 + 1/4-20 x 3/4 SHCS, 2419 to leg (est.) - 2 corner holes per leg | 3.0 | 24.0
Wheeled cart | Surfaces | 2637 | 1 | Laptop table panel, 13.84 x 24 in, Lite ACM .236 black | 31.9 | 31.9
Wheeled cart | Surfaces | 2637-cut | 1 | Panel cut-to-size charge, per panel | 16.13 | 16.13
Wheeled cart | Surfaces | 3321 | 4 | Bolt assembly: 1/4-20 x .5 FBHSCS + economy T-nut, panel to rail (countersink the panel) | 0.87 | 3.48
Wheeled cart | Finish | 2015 | 2 | 10 series 1 x 1 end cap (exposed 1010 ends) | 2.02 | 4.04
 |  |  |  | Total (before shipping/tax) |  | 1290.9

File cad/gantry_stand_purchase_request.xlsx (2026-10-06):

Purchase Request: Gantry Stand Materials (bench box + wheeled cart)
Vendor | 80/20 Inc., 1701 South 400 East, Columbia City, IN 46725 (https://8020.net)
Pricing | 80/20 online list prices as shown in the 8020.net cart on 2026-10-06
Saved order | 8020.net wish list "Gantry stand (bench box + wheeled cart)": https://8020.net/wishlist/index/index/wishlist_id/184227/
Line | Description | Part No. | Qty | Est. Unit Cost ($) | Extended ($)
1 | 1010 T-slotted aluminum profile, 1.00 x 1.00 in, four open T-slots, cut to 24.00 in (price includes $3.00 cut charge) | 1010 | 2 | 13.80
2 | 1010 T-slotted aluminum profile, 1.00 x 1.00 in, four open T-slots, cut to 22.00 in (price includes $3.00 cut charge) | 1010 | 5 | 12.90
3 | 1010 T-slotted aluminum profile, 1.00 x 1.00 in, four open T-slots, cut to 20.00 in (price includes $3.00 cut charge) | 1010 | 8 | 12.00
4 | 1010 T-slotted aluminum profile, 1.00 x 1.00 in, four open T-slots, cut to 45.71 in (price includes $3.00 cut charge) | 1010 | 1 | 23.57
5 | 1010 T-slotted aluminum profile, 1.00 x 1.00 in, four open T-slots, cut to 38.00 in (price includes $3.00 cut charge) | 1010 | 2 | 20.10
6 | 1010 T-slotted aluminum profile, 1.00 x 1.00 in, four open T-slots, cut to 13.00 in (price includes $3.00 cut charge) | 1010 | 1 | 8.85
7 | 2020 T-slotted aluminum profile, 2.00 x 2.00 in, eight open T-slots, cut to 4.71 in (price includes $3.18 cut charge) | 2020 | 4 | 8.50
8 | 2020 T-slotted aluminum profile, 2.00 x 2.00 in, eight open T-slots, cut to 16.07 in (price includes $3.18 cut charge) | 2020 | 4 | 21.34
9 | 10 Series 2-hole gusseted inside corner bracket | 4132 | 48 | 7.11
10 | Bolt assembly: 1/4-20 x .375" black button head socket cap screw with slide-in economy T-nut | 3416 | 108 | 0.71
11 | Flange mount swivel caster, 5 in soft rubber wheel, top brake, 300 lb rating | 2323 | 4 | 42.78
12 | 10 Series flange mount caster base plate | 2419 | 4 | 28.46
13 | Bolt assembly: 1/4-20 x .500" black flat head socket cap screw with slide-in economy T-nut | 3321 | 8 | 0.87
14 | 10 Series 1" x 1" end cap with push-in fastener | 2015 | 6 | 2.02
15 | Lite aluminum composite panel, 0.236 in thick, black, cut to 24 x 24 in (4.000 sq ft x $13.83, includes $16.13 cut charge) | 2637 | 1 | 71.45
16 | Lite aluminum composite panel, 0.236 in thick, black, cut to 13.84 x 24 in (2.307 sq ft x $13.83, includes $16.13 cut charge) | 2637 | 1 | 48.04
 | Subtotal (before shipping and tax)
Notes
 | Shipping and tax are not included above. 80/20's cart estimated UPS Ground shipping at $40.39 and tax at $75.72 (to the account's address on 2026-10-06), for an order total of about $1,337.68.
 | Quantities and cut lengths come from the CAD model of the stand (gantry_cart.py / cart_bom.py).
 | Blue cells are inputs (quantity, unit cost); Extended and Subtotal are formulas.

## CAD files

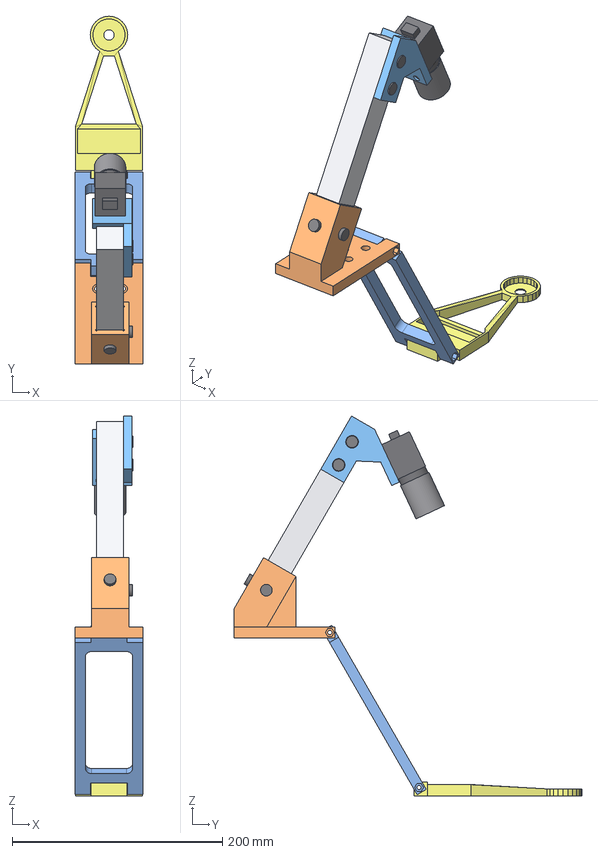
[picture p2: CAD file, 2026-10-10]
cad/camera_mount_assembly.step
65.0 x 330.4 x 361.2 mm
carriage_plate
mast_1010
clamp_screw_outer
clamp_tnut_outer
clamp_screw_pos_x
clamp_tnut_pos_x
camera_bracket
basler_ace2_placeholder
lens_placeholder
camera_m3_1
camera_m3_2
camera_m3_3
rail_bhscs_4
rail_bhscs_5
link1
xrite_i1_plate

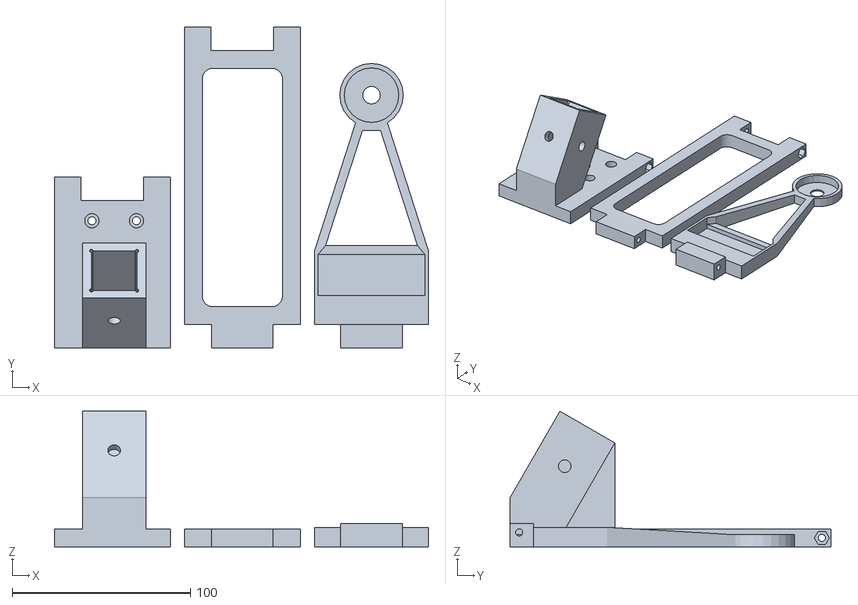
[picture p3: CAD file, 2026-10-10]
cad/chain_print_plate.stl
210.0 x 180.0 x 76.1

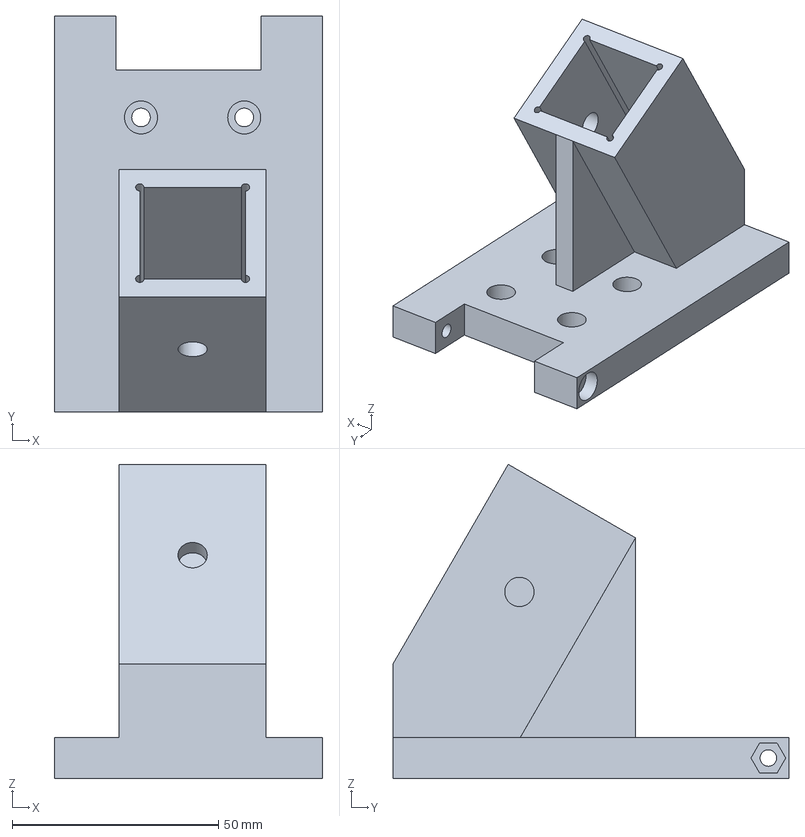
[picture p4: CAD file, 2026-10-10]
cad/carriage_hinge_plate.step
65.0 x 95.9 x 76.1 mm

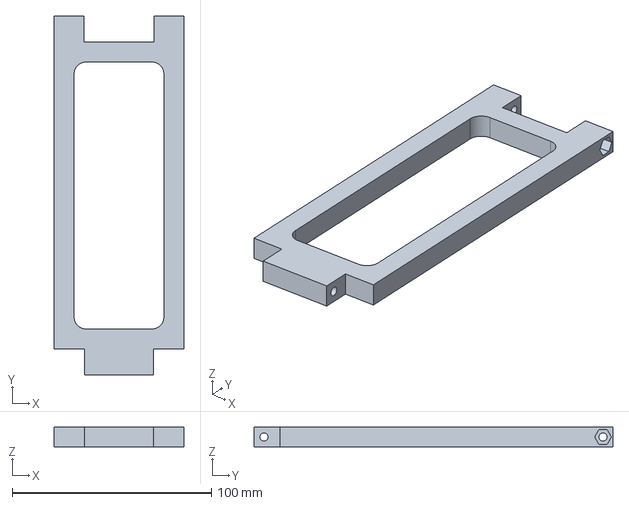
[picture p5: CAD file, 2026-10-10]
cad/chain_link_long.step
65.0 x 180.0 x 10.0 mm

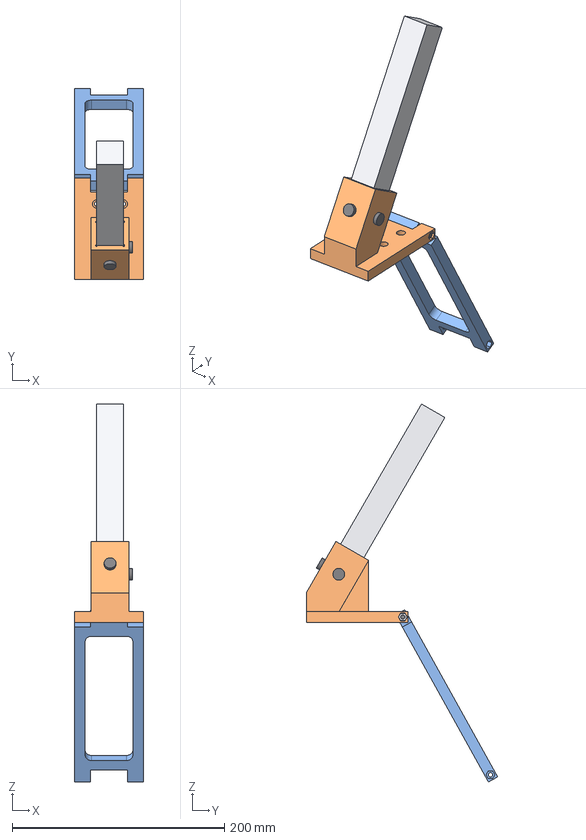
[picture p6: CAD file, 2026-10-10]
cad/carriage_chain.step
65.0 x 180.3 x 356.0 mm
carriage_plate
mast_1010
clamp_screw_outer
clamp_tnut_outer
clamp_screw_pos_x
clamp_tnut_pos_x
link1
screw1
nut1

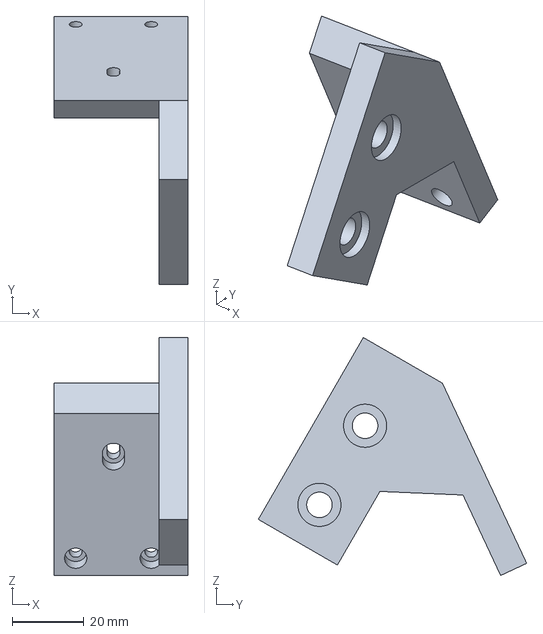
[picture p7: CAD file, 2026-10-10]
cad/camera_mount.step
37.2 x 74.6 x 66.2 mm

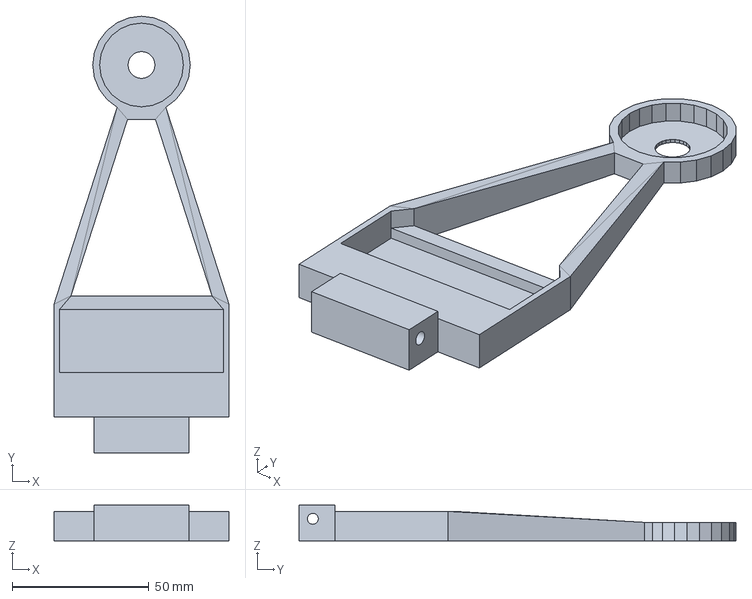
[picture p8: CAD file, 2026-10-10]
cad/xrite_i1_plate.step
64.0 x 159.7 x 13.1 mm

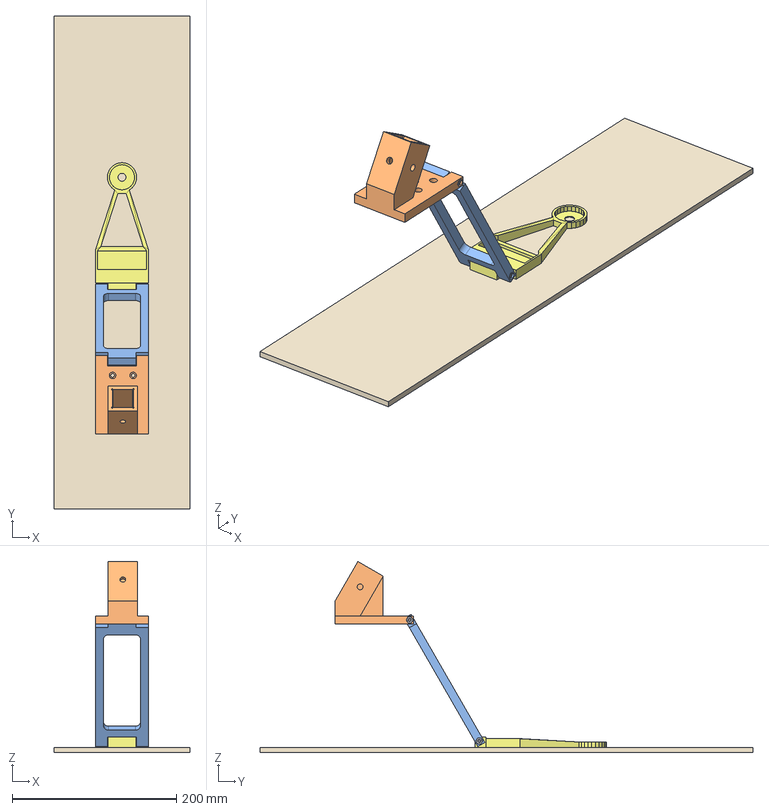
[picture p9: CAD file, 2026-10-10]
cad/carriage_chain_xrite.step
165.0 x 600.0 x 232.5 mm
carriage_plate
link1
screw1
nut1
screw2
nut2
xrite_i1_plate
table

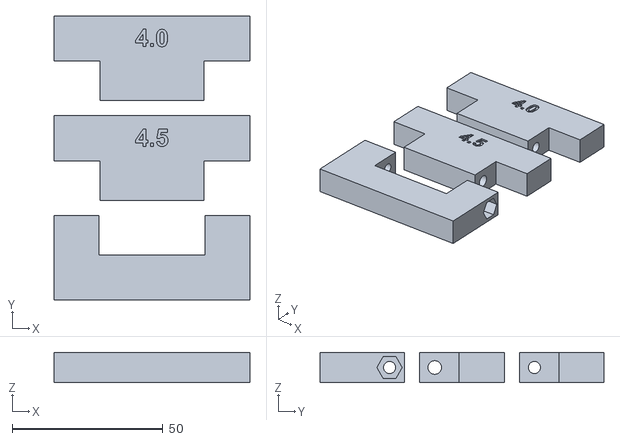
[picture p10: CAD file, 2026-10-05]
cad/knuckle_test_plate.stl
65.0 x 94.2 x 10.00

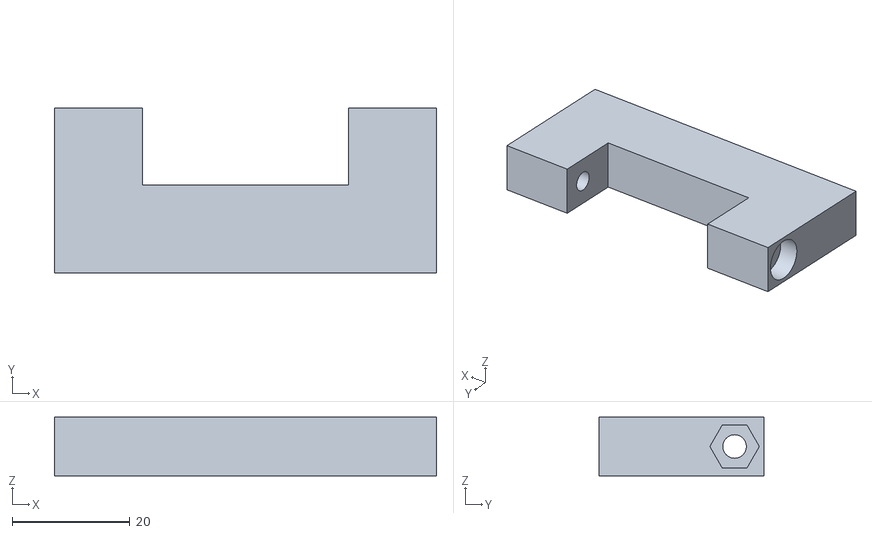
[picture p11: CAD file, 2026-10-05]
cad/knuckle_test_outer.stl
65.0 x 28.1 x 10.0

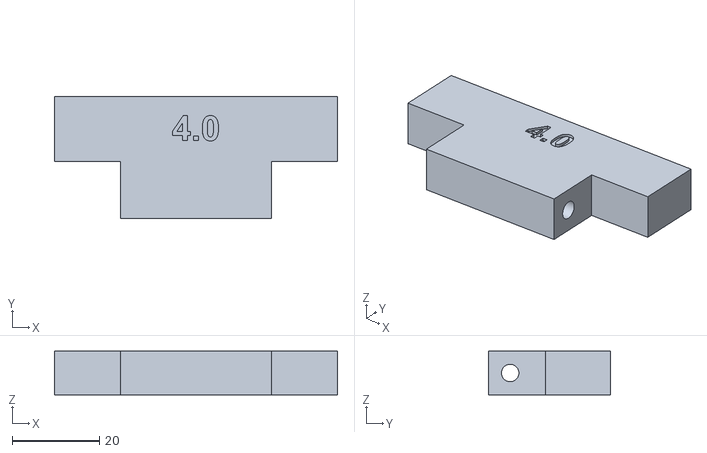
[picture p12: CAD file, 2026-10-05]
cad/knuckle_test_inner_4.0.stl
65.0 x 28.1 x 10.0

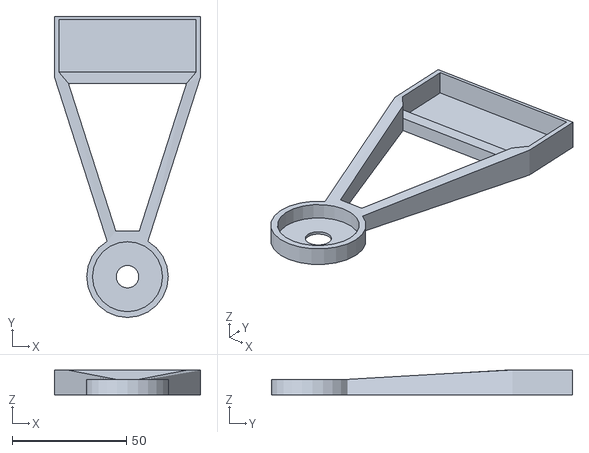
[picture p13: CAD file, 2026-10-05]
cad/xRitei1.stl
64.0 x 131.6 x 10.8

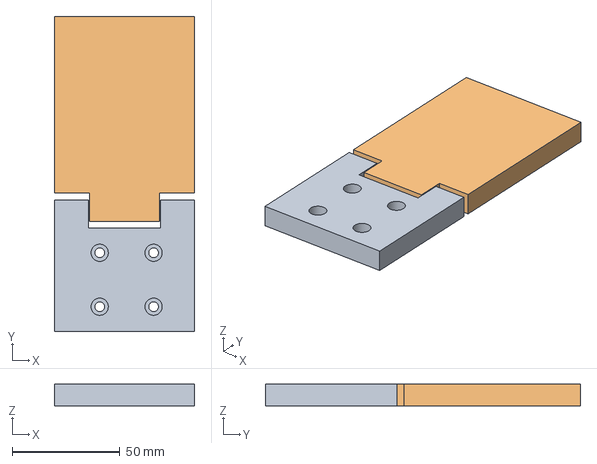
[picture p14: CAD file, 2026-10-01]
cad/carriage_link_pip.step
65.0 x 146.1 x 10.0 mm

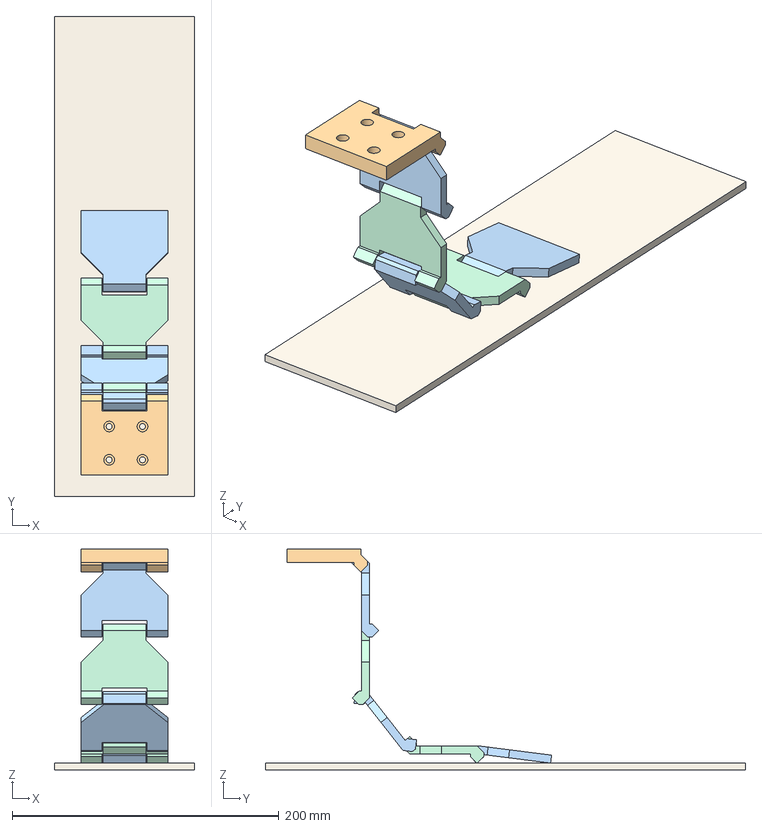
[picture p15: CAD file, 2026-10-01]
cad/folding_chain_draped.step
105.0 x 360.0 x 165.4 mm
plate_part
link1_part
link2_part
link3_part
link4_part
link5_part
table_part

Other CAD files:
cad/knuckle_test_inner_4.5.stl
cad/folding_chain.step
cad/carriage_link_pip_test.step
cad/hinged_plates.step
cad/camera_mount.stl
cad/carriage_hinge_plate.stl
cad/carriage_link_pip.stl
cad/carriage_link_pip_test.stl
cad/chain_link_long.stl
cad/folding_chain.stl
cad/fsk40_carriage_plate.step
cad/fsk40_carriage_plate.stl
cad/hinged_plate_a.stl
cad/hinged_plate_b.stl
cad/xrite_i1_plate.stl

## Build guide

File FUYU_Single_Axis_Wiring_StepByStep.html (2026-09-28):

FUYU TECHNOLOGY

# Wiring a Single Axis Step by Step

## One rail, one motor, one driver — from bare parts to a jogging axis

Scope: A complete single-axis build: 24 V supply → FMC4030 controller → FMDD50D40NOM driver → rail (motor + limit switches).
Wiring order: 1 Power supply · 2 Controller · 3 Driver · 4 Rail. Each stage ends with a verification step before you move on.
Axis used: Controller axis 1 — terminals 5V / PU1 / DR1, limits LP1 / LN1. (In the SDK this is axis index 0.)
Everything stays de-energized until §8. You wire the whole axis with the AC plug out.
Companion document: the full Dual-X Gantry Assembly & Wiring Manual — this guide is the learning subset of it.

## 1How the four boxes connect

Before touching a screwdriver, get the shape of the system in your head. There are only four boxes, and each one has exactly one job:

Box | Its one job | What goes in | What comes out
24 V supply | Turn wall AC into a 24 V DC bus | 100–220 VAC (L / N / earth) | 24 V+ and 24 V− that everything else drinks from
FMC4030 controller | Think. Decide where the axis should be | 24 V power, limit-switch signals, Ethernet commands from your PC | A stream of 5 V pulse + direction signals
FMDD50D40NOM driver | Turn tiny 5 V pulses into real motor current | 24 V power (muscle) + 5 V pulse/direction (instructions) | Two coil currents, A and B, to the motor
The rail | Turn rotation into linear travel, and report its ends | Motor coil currents; 24 V for the switches | Motion, plus limit/home signals back to the controller

┌──────────── everything drinks from this bus ────────────┐ │ │ AC 100–220 V ──► [ 24 VDC SUPPLY ] ══ 24V+ / 24V− ═══╦═══════════╦════════════╗ L N ⏚ ║ ║ ║ ▼ ▼ ▼ [ CONTROLLER ] [ DRIVER ] [ LIMIT SW ] FMC4030 FMDD50 FSK40 ×2 │ │ │ 5V / PU1 / DR1 └──────────►┤ │ (pulse + direction, 5 V) │ │ │ A+ A− B+ B− │ └──────► [ MOTOR ] on the RAIL LP1 / LN1 ◄─────── black signal wires ─────────┘ (the rail tells the controller where its ends are)

The one idea that makes all of this click Two completely separate things travel between the controller and the driver: instructions and muscle. The controller only ever sends instructions — a 5 V pulse train that carries almost no current (~15 mA). The muscle comes from the 24 V bus straight into the driver, and the driver decides how to push it through the motor coils. That is why the motor's power never flows through the controller, and why a mistake on the signal side makes the motor silent while a mistake on the power side makes it hot.

### Why we wire in this order

Stage 1Power supplyBuild the 24 V bus and prove it is +24 V and correctly polarised, with nothing attached to damage.

Stage 2ControllerGive the brain power and earth, and a network cable. Nothing moves yet, so mistakes are cheap.

Stage 3DriverSet its DIP switches, feed it 24 V, then run the three signal wires from the controller.

Stage 4The railMotor coils into the driver, limit switches back to the controller. The moving parts go last.

Each stage is verifiable on its own. That is the whole point of the order: if something is wrong, you know it belongs to the stage you just finished, not to a haystack of forty wires.

## 2Parts & tools for one axis

Qty | Item | Model / spec | Notes
1 | DC power supply | 24 VDC, ≥ 4 A for a single axis | AC 100–220 V input. One motor draws 2.0 A; 4–5 A gives comfortable headroom.
1 | Motion controller | FMC4030 (3-axis) | You will use only axis 1. Axes 2 and 3 stay empty.
1 | Stepper driver | FMDD50D40NOM (DC 20–50 V, 1.0–4.0 A/phase) | 24 V is well inside its input range.
1 | Stepper motor | 57HS056TF075A-03 (NEMA 23, 2-phase, 1.8°, 2.0 A/phase, ≥ 80 N·cm) | Already mounted on the rail with its coupling tightened.
2 | Limit / home switch | FSK40 photoelectric, NPN normally-open, 5–24 V | One at each end of travel. One switch works, two is better.
1 | Ethernet cable | Standard RJ45 | Controller CN3 to your PC.
— | Wiring | Hook-up wire, ferrules, PE (earth) wire, fuse or breaker on the AC side | Ferrules on every stranded end that enters a screw terminal.

#### Tools

Small flat and Phillips screwdrivers, hex keys, wire stripper/crimper, ferrules, a multimeter (you will use continuity and DC volts constantly), label tape or a marker, and a PC with an Ethernet port.

Label both ends of every wire as you make it. Two minutes with tape now saves an hour of tracing later. A single axis is 13 connections; write what each one is.

## 3Safety rules

⚠ The supply's input side carries 100–220 VAC. Do all wiring with the system fully de-energized and the AC plug physically removed — not just switched off. Mains termination should be done by someone qualified to do it. Never work on live terminals, and never leave AC terminals uncovered.

#### Do

- Wire everything with power off, plug out.
- Bond the controller's PE terminal and the machine frame to protective earth.
- Check 24 V polarity with a meter before anything is connected to the bus.
- Use ferrules on stranded wire entering screw terminals, and tug-test every wire.
- Keep motor and 24 V power wiring physically away from signal and Ethernet runs.

#### Don't

- Never plug or unplug the motor while the driver is powered — it can destroy the driver's output stage.
- Don't exceed DC 50 V into the driver's V+/V−.
- Don't split a motor coil pair across A and B (see §7).
- Don't feed 24 V into the driver's PU/DR inputs — those are the 5 V side.
- Don't make your first jog a long one. Millimetres first.

## Stage 1The power supply

Goal: a 24 V DC bus you have measured and trust, with nothing else connected to it yet.

Everything downstream assumes this bus is correct. If the polarity is backwards here, you will find out by destroying a controller — so this stage is short, and it ends with a meter reading.

AC side (dangerous) DC side (safe to handle when AC is out) ─────────────────── ─────────────────────────────────────── L ──► L ┌─────────────────┐ V+ ──► 24V+ bus ══► controller, driver, switches N ──► N │ 24 VDC SUPPLY │ V− ──► 24V− bus ══► controller, driver, switches ⏚ ──► ⏚ └─────────────────┘ (some supplies label these +V / −V or DC OK)

Step 1.1 — Mount the supply and confirm its input voltage selector

Fix the supply in the cabinet where its terminals are reachable and its vents are not blocked. If it has a 115 V / 230 V selector switch, set it to match your mains now — this is the single most expensive thing to get wrong on this page.

Step 1.2 — Land the AC input

With the plug out, connect mains to the supply's input terminals: L (live), N (neutral), and ⏚ (earth). Put a fuse or breaker upstream. Fit the terminal cover and strain relief before you go any further.

Step 1.3 — Build the 24 V bus

You have one supply feeding three consumers (controller, driver, two switches), so make a small distribution point rather than stacking four wires under one screw:

- Run one wire from the supply's V+ to a 24 V+ distribution point — a small terminal block, a bus bar, or two ferrules doubled into one screw if that is all you have.
- Do the same from V− to a 24 V− distribution point.
- Pick a colour convention and keep it for the whole build: this guide uses orange for 24 V+ and blue for 24 V−.

Leave both distribution points otherwise empty for now. Nothing else connects in this stage.

Step 1.4 — Prove the bus, then kill it again

Plug in the AC and switch on, with nothing connected downstream of the bus. Set your meter to DC volts and measure from 24 V+ to 24 V−.

- You want roughly +24 V (anything ≈ 23.5–25 V is fine; many supplies have a trim pot).
- A negative reading means your meter leads are swapped, not the supply — swap the leads and confirm which terminal is genuinely positive. Label them.
- Also check 24 V− to earth and 24 V+ to earth: neither should read a dead short.

Then switch off and pull the AC plug. The rest of the build happens dead.

✔ Verify before Stage 2

- Meter reads ≈ +24 V from the 24 V+ point to the 24 V− point.
- Both bus points are clearly labelled + and −, and you are certain which is which.
- AC terminals are covered; the plug is out; the supply is now dead.

## Stage 2The controller

Goal: the FMC4030 powered, earthed, and reachable over Ethernet. Three power wires and one network cable.

The controller is the cheapest stage to wire and the easiest to damage, so it gets its own step. It takes 24 V on VN+/VN− — the same bus the driver uses — plus an earth bond on PE.

24V+ bus ────► VN+ ┐ 24V− bus ────► VN− ├─ FMC4030 power/limit edge earth ⏚ ────► PE ┘ PC ──── RJ45 ────► CN3 (default 192.168.0.30 : 8088)

Step 2.1 — Find the two terminal banks

The FMC4030 has terminals along two opposite edges. Orient yourself before wiring — terminals that happen to sit across from each other are not related:

- One edge is the signal / output edge: the per-axis 5V, PU, DR groups plus the OP outputs.
- The other is the power / limit / input edge: VN+, VN−, PE, then the LP/LN/GND limit groups, then IN0–IN3.

In this stage you only touch the first three terminals of the power edge. The full map is in §11.

Step 2.2 — Wire controller power

With the supply dead:

From | To controller | Wire
24 V+ bus | VN+ | 24 V+
24 V− bus | VN− | 24 V−

Double-check these two against your labels before moving on. Reversed polarity on VN+/VN− is the classic way to kill a controller on its first power-up.

Step 2.3 — Bond PE to earth

Run a wire from the controller's PE terminal to the machine frame, and from the frame to protective earth. PE is chassis ground — it is a safety and noise path, not a signal return, so do not use it in place of VN− or a limit GND.

Step 2.4 — Plug in Ethernet and set up the PC

Run an RJ45 cable from CN3 to your PC (directly, or through a switch/router). The controller ships on a fixed address:

- Controller: IP 192.168.0.30, port 8088.
- Set your PC's adapter to the same subnet — e.g. IP 192.168.0.35, mask 255.255.255.0, gateway 192.168.0.1.

You will test the link in §9. CN1 (RS-232 DB9) and CN2 (RS-232/485 on RJ45) exist but are not needed for bring-up — leave them alone.

Resist the urge to power up and look at the lights. There is nothing to learn from it yet, and every power-up with half-finished wiring is a chance to short something. The single power-on happens in §9, after the checklist.

✔ Verify before Stage 3

- VN+ traces back to 24 V+, VN− to 24 V− — confirmed by continuity, not by memory.
- PE is bonded to the frame and to earth.
- Ethernet is seated in CN3; the PC adapter is on 192.168.0.x.
- Still de-energized.

## Stage 3The driver

Goal: DIP switches set correctly, 24 V in, and the three signal wires from controller axis 1. Motor still unplugged.

The driver is where most first-time mistakes live, so it splits into three parts: switches first (they are awkward to reach once wired), then power, then signals. Like the controller, the driver has terminals on two ends — a control-signal end (PU±, DR±, MF±, COM24V) and a power/motor end (V+, V−, A+, A−, B+, B−).

### 3a — Set the DIP switches (do this first)

There are eight switches. SW1–SW3 set the output current, SW4 sets the mode, and SW5–SW8 set microstepping.

SW4 must be OFF. SW4 = OFF selects pulse / subdivision mode, which is what the FMC4030's PU/DR signals require. With SW4 = ON the driver is in I/O mode and will ignore your pulses completely — the motor simply sits there holding, and you will spend an afternoon checking wiring that was fine all along.

Step 3.1 — Set the current to match the motor (2.0 A)

The 57HS motor is rated 2.0 A per phase. Set the driver to that and no more — too low is weak and skips steps, too high runs hot. Peak current is the operating figure × 1.4.

Operating A | 1.0 | 1.2 | 1.5 | 2.0 ★ | 2.5 | 3.0 | 3.5 | 4.0
Peak A | 1.4 | 1.7 | 2.1 | 2.8 | 3.5 | 4.2 | 4.9 | 5.6
SW1 | ON | OFF | ON | OFF | ON | OFF | ON | OFF
SW2 | ON | ON | OFF | OFF | ON | ON | OFF | OFF
SW3 | ON | ON | ON | ON | OFF | OFF | OFF | OFF

★ For the 57HS motor (2.0 A): SW1 = OFF · SW2 = OFF · SW3 = ON

Step 3.2 — Choose microstepping

Microstepping divides each 1.8° full step into smaller ones: smoother and quieter, but more pulses per revolution, so a high setting caps your top speed. 1600 steps/rev is a good general-purpose starting point.

Steps/rev | 200 | 400 | 800 | 1600 ★ | 3200 | 6400 | 12800 | 25600
SW5 | ON | OFF | ON | OFF | ON | OFF | ON | OFF
SW6 | ON | ON | OFF | OFF | ON | ON | OFF | OFF
SW7 | ON | ON | ON | ON | OFF | OFF | OFF | OFF
SW8 | ON | ON | ON | ON | ON | ON | ON | ON

★ Suggested start (1600 steps/rev): SW5 = OFF · SW6 = OFF · SW7 = ON · SW8 = ON · and SW4 = OFF

A second bank of values (1000–40000 steps/rev) lives behind SW8 = OFF; see the driver datasheet if you ever need it.

Write the number down. Steps/rev is how the software converts millimetres into pulses. If you change this switch later without telling the software, every distance you command will be wrong by that ratio.

### 3b — Driver power (the muscle)

Step 3.3 — Feed the driver 24 V

From | To driver | Wire
24 V+ bus | V+ | 24 V+
24 V− bus | V− | 24 V−

This is the only power the motor ever sees — all motor current is manufactured here, from this pair of wires. Use conductors sized for a couple of amps and keep them short. The driver accepts DC 20–50 V; 24 V sits comfortably in range.

### 3c — Signal wiring (the instructions)

Three wires carry everything the controller has to say. They are wired common-anode: the controller's 5 V feeds the driver's two opto-isolator anodes (PU+ and DR+, tied together), and the controller's PU1 and DR1 pins sink the other side of those optos.

FMC4030 — axis 1 FMDD50D40NOM driver ──────────────── ─────────────────── 5V ────────────────┬──────────────► PU+ (opto anode) └──────────────► DR+ (opto anode) PU1 ───────────────────────────────► PU− pulse / step (falling-edge active) DR1 ───────────────────────────────► DR− direction MF+ MF− ── leave OPEN COM24V ── leave OPEN (24 V-signal mode only)

Step 3.4 — Run the three signal wires

Controller (axis 1) | Driver | What it carries
5V | PU+ and DR+ (bridge them) | 5 V supply for both opto-isolator LEDs. Carries ~15–17 mA per input and no motor current at all.
PU1 | PU− | The pulse train. One pulse = one microstep.
DR1 | DR− | Direction: which way the next pulses go.

Note that 5V goes to two terminals — take one wire from the controller to the driver and bridge PU+ to DR+ at the driver end, or land two wires on the controller's 5V. Either is fine.

Use the controller's 5 V here — never 24 V. The PU/DR inputs in this common-anode wiring expect 5 V. Feeding 24 V into them damages the opto inputs. The driver's COM24V terminal exists for a different (24 V-signal) wiring scheme that we are not using — leave it open.

MF+ / MF− stay disconnected. MF is "motor free" — energising it releases the motor so the shaft spins freely with no holding torque. You almost always want holding torque, so leave these two terminals empty. An axis that mysteriously has no torque is usually an MF wire someone added helpfully.

Keep signal and power apart. Run these three signal wires away from the 24 V and motor-coil runs, and keep them reasonably short. Stepper motor wiring is electrically noisy; a pulse line taped alongside it can pick up phantom steps.

✔ Verify before Stage 4

- SW4 = OFF. Look at it again — it is the most common single-axis failure.
- Current set to 2.0 A (SW1 OFF, SW2 OFF, SW3 ON); microstepping noted down (1600 suggested).
- V+/V− polarity correct, verified with continuity back to the labelled bus.
- Controller 5V reaches both PU+ and DR+; PU1→PU−; DR1→DR−.
- MF+, MF−, COM24V all empty. Axis 2 and axis 3 terminals on the controller all empty.

## Stage 4The rail

Goal: motor coils landed on the driver, and both limit switches reporting back to the controller. Then you are done wiring.

The rail contributes two things electrically: a motor that takes current from the driver, and limit switches that send signals back to the controller. Note they connect to different boxes — a very common point of confusion. The motor never touches the controller; the switches never touch the driver.

### 4a — Motor → driver

The 57HS motor has four leads on an XH-4 connector: two per coil. The colours map straight across:

Pin | Motor colour | Coil | Driver terminal
1 | Black | A (A+) | A+
2 | Green | Ā (A−) | A−
3 | Red | B (B+) | B+
4 | Blue | B̄ (B−) | B−

Step 4.1 — Confirm the coil pairs with a meter

Before landing anything, prove which wires belong together. With the motor unplugged from everything, measure resistance between pairs:

- Black ↔ Green should read about 0.75 Ω — they are one coil (A).
- Red ↔ Blue should read about 0.75 Ω — they are the other coil (B).
- Any A wire ↔ any B wire should read open. The two coils are electrically separate inside the motor.

If your motor's colours differ from the table, trust the meter and the coil pairs, not the colour chart.

Step 4.2 — Land the four coil wires

With power off, connect Black→A+, Green→A−, Red→B+, Blue→B−.

Pairing matters more than polarity. Getting A+ and A− backwards just reverses the axis direction — annoying, harmless, and fixable. Splitting a pair (say Black and Red on A) means neither coil gets a complete circuit, and the motor will buzz, vibrate in place, or refuse to turn. If the motor misbehaves on first jog, this is the first thing to re-check.

Never connect or disconnect the motor while the driver is powered. Interrupting coil current in a live driver produces a voltage spike that can take out the output stage. Motor in place now, while everything is dead — and power down before you ever touch it again.

### 4b — Limit / home switches → controller

Each FSK40 is a photoelectric switch with a slot: a flag on the moving carriage passes through the slot and trips it. On the FMC4030 these switches do double duty — end-of-travel protection and the home/origin reference the zero-return routine drives to.

The switches must be NPN, normally-open (NO). The FMC4030's limit inputs are low-level active — the switch works by pulling the signal line down. A PNP switch will never read correctly no matter how you wire it. Verify against the label on your own switch.

FSK40 switch FMC4030 — axis 1 limit group ──────────── ──────────────────────────── Brown ──────► 24V+ bus LP1 ◄── black wire of the positive-end switch Blue ──────► 24V− bus LN1 ◄── black wire of the negative-end switch (home) Black ──────► LP1 or LN1 GND ◄── axis-1 limit ground (sits right after LN1)

Step 4.3 — Mount the sensors and the flag

If this is not already done mechanically: fix each sensor body to the rail so the moving flag passes through the optical gap without touching anything, and fix the flag to the carriage.

- Put the negative-end sensor at the home/zero end of travel, and the positive-end sensor at the far end.
- Leave a few millimetres of margin before the hard mechanical stop, so the switch trips before the carriage bottoms out.
- Slide the carriage by hand through both sensors and watch each sensor's indicator LED change state. Fix any mechanical interference now.

Step 4.4 — Wire both switches

Both switches share the 24 V bus; only their black signal wires differ.

Switch wire | Negative-end switch (home) | Positive-end switch
Brown (+24 V) | 24 V+ bus | 24 V+ bus
Blue (0 V) | 24 V− bus | 24 V− bus
Black (signal) | Controller LN1 | Controller LP1

Use the GND terminal that sits in the axis-1 limit group, immediately after LN1, as this pair's limit ground / return. All three limit GND terminals on the controller are internally common, so electrically any of them works — but keeping each pair in its own group keeps the harness readable.

Only fitting one switch? Put it at the home end on LN1. You get homing and protection where the carriage returns, and you then rely on software soft-limits at the far end. Leave LP1 empty.

Wrong end trips? If the software later shows "+" tripping when you move toward the negative end, the two black wires are simply swapped. Power off and exchange them at LP1/LN1.

✔ Verify — wiring complete

- Coil pairs metered: Black+Green ≈ 0.75 Ω, Red+Blue ≈ 0.75 Ω, A↔B open.
- Motor landed on A+/A−/B+/B− with pairs intact, done with power off.
- Both switches: brown→24 V+, blue→24 V−, black→LP1 (far end) / LN1 (home end).
- Axis-1 GND used as the limit return. LP2/LN2/LP3/LN3 empty.
- Flag passes cleanly through both sensor slots by hand, LEDs changing state.

## 8Pre-power checklist

Thirteen connections, still de-energized, meter in hand. Walk the list before the plug goes in.

- AC landed correctly on the supply's L / N / ⏚; voltage selector correct; terminals covered; fuse or breaker upstream.
- 24 V bus polarity verified and labelled; no short from either rail to earth.
- Controller VN+ → 24 V+, VN− → 24 V−. Confirmed, not assumed.
- Controller PE bonded to frame and protective earth.
- Driver V+ → 24 V+, V− → 24 V−.
- Driver SW4 = OFF (pulse mode). Current 2.0 A: SW1 OFF, SW2 OFF, SW3 ON. Microstepping set and written down.
- Signals: 5V → PU+ & DR+; PU1 → PU−; DR1 → DR−.
- MF+, MF−, COM24V left open.
- Motor coil pairs verified by continuity; four coil wires on A+/A−/B+/B−; connector seated while unpowered.
- Limit switches are NPN-NO; brown/blue on the 24 V bus; black wires on the correct LP1/LN1.
- Nothing landed on axis 2 or axis 3 terminals.
- Ethernet in CN3; PC adapter on 192.168.0.x / 255.255.255.0.
- No stray strands, no terminal touching its neighbour, every screw tight, every wire tug-tested.
- Carriage sitting mid-travel (not against a hard stop), and the path is clear of hands and tools.

## 9First power-on & first jog

1. Energize. Plug in and switch on. The supply LED should light, the controller and driver power LEDs should come on, and the driver's red ALM fault light should stay off. If ALM is lit, power down immediately and go to §10.
2. Listen and feel. The motor should be silently holding — try turning the shaft or coupling by hand; it should resist noticeably. No resistance means either no 24 V at the driver or an accidentally-energised MF.
3. Test the network. From the PC: ping 192.168.0.30 -t. You want steady replies. No replies means the PC is not on the controller's subnet, or the cable is not in CN3.
4. Connect the software. Launch the controller software and connect to 192.168.0.30 : 8088. If the connection drops after about a minute of inactivity, that is the controller's idle timeout by design — just reconnect.
5. Check the limit switches before commanding any motion. In the status panel, slide the carriage by hand and trip each switch. Confirm the home-end switch registers as LN1 (negative) and the far-end switch as LP1 (positive). If they are reversed, power down and swap the two black wires. Fix this now — a limit wired to the wrong end cannot stop an overrun.
6. First jog: a few millimetres, low speed. Command the smallest move your software allows on axis 1. Watch for:
  - Smooth rotation and travel → coils are paired correctly.
  - Buzzing, vibration in place, or no rotation → power down and re-check the coil pairing (§4a).
  - Nothing at all, motor still holding → almost certainly SW4 is ON, or PU/DR is mis-wired.
7. Check the direction convention. Jog positive and confirm the carriage moves toward the positive-end switch. If it goes the wrong way, either invert the direction in software, or power down and swap the motor's A+ ↔ A−. For a single axis, software is the easier fix.
8. Confirm the limits actually stop motion. At low speed, jog toward each end and confirm the axis stops when the switch trips. Stay ready to cut power.
9. Home the axis. Run the zero-return / homing routine to LN1 and set that position as zero. Your axis now has a repeatable origin, which is what makes every coordinate you command afterwards meaningful.

Moving on to software. In the SDK this axis is index 0 (the terminals labelled PU1/DR1). The controller counts axes from zero while the silkscreen counts from one — an off-by-one worth remembering. The software also needs the steps/rev you set in Step 3.2 to convert millimetres into pulses.

Single axis complete. Smooth jogging in both directions, both limits verified, and a repeatable home position means your electrical build is sound. Adding a second axis is the same four stages again on 5V/PU3/DR3 with limits on LP3/LN3 — the bus and the controller are already there.

## 10Troubleshooting

Symptom | Most likely cause | Fix
Motor holds but does nothing on jog | SW4 is ON (I/O mode instead of pulse mode) | Set SW4 = OFF. Then verify 5V→PU+/DR+, PU1→PU−, DR1→DR−
Motor buzzes / vibrates but won't rotate | A coil pair is split across A and B | Re-verify by continuity: A = Black+Green, B = Red+Blue (≈0.75 Ω each, open between them)
No holding torque, shaft spins freely | No 24 V at the driver, or MF is energised | Meter V+/V− at the driver; disconnect anything on MF+/MF−
Axis runs the wrong direction | Direction convention | Invert direction in software, or power off and swap the motor's A+ ↔ A−
Driver red ALM light on | Over-temperature (>80 °C), over-current/short, or a motor wiring fault | Power down, inspect motor wiring for shorts, let it cool, improve spacing/airflow, then power-cycle
Motor weak, skips steps under load | Current set too low | Set 2.0 A: SW1 OFF, SW2 OFF, SW3 ON. Also lower acceleration
Motor runs very hot | Current set above the motor's 2.0 A rating | Drop to the 2.0 A setting; note some warmth is normal for steppers
Limit never triggers | Wrong switch type (PNP), or black wire on the wrong terminal | Must be NPN normally-open; verify brown=24 V+, blue=0 V, black=signal on LP1/LN1
Limit always shows triggered | Signal line pulled low permanently, or the flag is sitting in the slot | Move the carriage clear; check the black wire isn't shorted to 0 V; confirm the sensor LED changes state
"Positive" trips when moving negative | LP1 and LN1 swapped | Power off and exchange the two black signal wires
Random extra steps / positions drift | Pulse wire picking up noise from motor/power runs | Re-route signal wires away from 24 V and motor cabling; shorten them; confirm PE is bonded
No ping reply from the controller | PC not on the controller's subnet | Set the PC adapter to 192.168.0.x / 255.255.255.0; confirm the cable is in CN3
Connection drops after about a minute | Controller idle timeout — by design | Keep interacting, or simply reconnect
Nothing powers up at all | AC not landed, wrong voltage selector, or blown fuse | Power down, pull the plug, and re-check Stage 1 end to end

## 11Terminal cheat-sheet

Every terminal this single-axis build touches, and every one it deliberately leaves alone.

### 11.1 FMC4030 controller

Terminal | Edge | Used here? | What it is
VN+ | Power / limit / input | Yes → 24 V+ bus | 24 V controller power, positive
VN− | Power / limit / input | Yes → 24 V− bus | 24 V controller power, negative
PE | Power / limit / input | Yes → frame + earth | Protective earth / chassis ground
LP1 | Power / limit / input | Yes → far-end switch black | Axis 1 positive limit
LN1 | Power / limit / input | Yes → home-end switch black | Axis 1 negative limit / home
GND (axis-1 group) | Power / limit / input | Yes → limit return | Axis 1 limit ground (all limit GNDs are internally common)
5V (axis 1) | Signal / output | Yes → driver PU+ & DR+ | 5 V out for the driver's opto anodes
PU1 | Signal / output | Yes → driver PU− | Pulse / step output, falling-edge active
DR1 | Signal / output | Yes → driver DR− | Direction output
5V/PU2/DR2, LP2/LN2/GND | Both | No — leave empty | Axis 2. Unused in a single-axis build
5V/PU3/DR3, LP3/LN3/GND | Both | No — leave empty | Axis 3. This is where a second axis would go
OP1–OP4 + GND | Signal / output | No | Four 24 V open-drain outputs, sink ≤ 300 mA (relays, valves, indicators)
IN0–IN3 + GND | Power / limit / input | No | Four 24 V digital inputs, active low (buttons, sensors, e-stop sense)
CN3 | — | Yes → PC | Ethernet. Default 192.168.0.30 : 8088
CN1 / CN2 | — | No | RS-232 DB9 / RS-232+485 on RJ45. Not needed for bring-up

### 11.2 FMDD50D40NOM driver

Terminal | End | Used here? | What it is
V+ | Power / motor | Yes → 24 V+ bus | DC power in, 20–50 V
V− | Power / motor | Yes → 24 V− bus | DC power in, 0 V
A+ | Power / motor | Yes | Motor coil A+ — Black
A− | Power / motor | Yes | Motor coil A− — Green
B+ | Power / motor | Yes | Motor coil B+ — Red
B− | Power / motor | Yes | Motor coil B− — Blue
PU+ | Control signal | Yes → controller 5V | Pulse opto anode
PU− | Control signal | Yes → controller PU1 | Pulse / step input, falling-edge active
DR+ | Control signal | Yes → controller 5V | Direction opto anode
DR− | Control signal | Yes → controller DR1 | Direction input
MF+ / MF− | Control signal | No — leave open | Motor-free / enable. When energised the driver releases the motor (no holding torque)
COM24V (HSC) | Control signal | No — leave open | 24 V signal common, for 24 V-signal mode only. Not used in 5 V common-anode wiring

### 11.3 The whole axis on one line

SUPPLY V+ ──► 24V+ ──┬──► CTRL VN+ ┌──► DRV V+ ┌──► SW brown (both switches) V− ──► 24V− ──┼──► CTRL VN− │ DRV V− ◄───┤ SW blue ⏚ ────────────────► CTRL PE ────┘ └────────────────── CTRL 5V ──► DRV PU+ & DR+ DRV A+ ──► Black ┐ CTRL PU1 ──► DRV PU− DRV A− ──► Green ├─ MOTOR on the rail CTRL DR1 ──► DRV DR− DRV B+ ──► Red │ DRV B− ──► Blue ┘ CTRL LP1 ◄── black, far-end switch 13 connections total: CTRL LN1 ◄── black, home-end switch 3 controller power · 2 driver power CTRL GND ◄── limit return 3 signal · 4 motor coil · 2 limit signal (+ the shared 24 V taps and Ethernet)

FUYU FMC4030 — Single-Axis Wiring, Step by Step. Learning guide for one axis on controller axis 1 (5V/PU1/DR1, LP1/LN1) — SDK axis index 0. Values compiled from the FUYU OEM documentation and the full Dual-X Gantry Assembly & Wiring Manual; verify against the labels on your own hardware before connecting. Revision 1.0.

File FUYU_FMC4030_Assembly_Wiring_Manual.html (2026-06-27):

FUYU TECHNOLOGY

# FMC4030 Dual-X Gantry System Assembly & Wiring Manual

## Hardware build guide — controller, stepper drivers, motors & limit switches

Configuration: Gantry — two parallel X rails (X-Left & X-Right) driven in hardware lockstep from a single controller axis, with a Y cross-beam riding across them.
System: FMC4030 controller · FMDD50D40NOM drivers (×3) · 57HS056TF075A-03 stepper motors (×3) · FSK40 NPN limit switches
Axis mapping: Controller axis 1 → both X drivers (shared PU/DR) · axis 2 unused · axis 3 → Y
Scope: Mechanical assembly and electrical wiring only. Software/SDK setup is covered separately.
Document revision: 1.0 · Compiled from FUYU OEM documentation

## 1System Overview

This is a dual-X gantry. Two parallel rails — X-Left and X-Right — run in the same direction and move together; a Y cross-beam spans between them and travels along their length. Each motor keeps its own FMDD50D40NOM driver, but the two X drivers share one controller axis — they receive the same pulse and direction signals, so the two rails step in perfect hardware lockstep and cannot drift out of sync. The Y beam has its own axis. The gantry is squared mechanically at assembly (it is not squared electronically).

The FMC4030 is a pulse-type, 3-axis motion controller built around a 32-bit ARM chip. It generates pulse (PU) and direction (DR) signals for three external stepper drivers, reads the axis limit/home switches (this build uses four — a positive/negative pair on X-Left and a pair on Y), and provides 4 digital inputs and 4 digital outputs. A host PC connects over Ethernet (default 192.168.0.30 : 8088).

#### Axis mapping

Physical axis | Controller channel | Pulse / Dir / 5V | Limit inputs
X-Left (gantry rail 1) | Axis 1 (both X drivers share this axis) | PU1 / DR1 / 5V | LP1 / LN1
X-Right (gantry rail 2) | | | none — no switch fitted
Y (cross-beam) | Axis 3 | PU3 / DR3 / 5V | LP3 / LN3

Axis 2 (PU2 / DR2) and its limit inputs (LP2 / LN2) are unused — both X drivers are fed from axis 1.

Colour key: X-Left rail X-Right rail Shared X signal (both rails) Y

Blue = X-Left rail/driver/motor, green = X-Right rail/driver/motor, the blue-green split = the one controller axis that feeds both X drivers, purple = Y. Shared terminals (power, ground, PE, generic I/O) are left uncoloured.

#### Physical layout (isometric)

Figure 1 — Dual-X gantry: two X rails with motors at the same end & orientation (wired identically), and a longer Y cross-beam whose Y-axis motor at one end drives the carriage (Y travel exceeds X travel). The four FSK40 limit switches are side-mounted — the X pair on the outside face of the left rail, the Y pair on the viewer-side face of the beam. The control electronics on the base are the FMC4030 controller, three stepper drivers, and a 24 V power supply. A cable carrier (drag chain) runs along the left X rail.

Signal flow and power:

[ PC ] --Ethernet--> [ FMC4030 ] --PU/DR (5V)--> [ 3× FMDD50D40NOM ] --A/B--> [ 3× 57HS motor ] ^ | LP/LN limit signals (24V NPN, 4 switches: X pair + Y pair) [ FSK40 limit switches ] 24 VDC bus powers: controller (VN+/VN-), all three drivers (V+/V-), and all limit switches (brown/blue).

Gantry essentials (read before wiring) Because both X drivers share one controller axis, the two rails are synchronised in hardware — but two things still matter:

- Wire both X motors identically — no reversal needed. Both rails are mounted the same way (same orientation, motors on the same end), so the shared direction signal moves both carriages the same physical direction. Use the standard coil colours on both motors. (Only a mirror-mounted build would need one motor's A+/A− swapped — not your case.) The §14 jog test confirms direction; see §8.
- Squaring is mechanical. The controller can't move one rail relative to the other, so the gantry's square comes entirely from the build (§5.1) and is held by the rigid beam.

Build order (recommended) Mechanical assembly → set driver DIP switches → power distribution → motor-to-driver → driver-to-controller → limit switches → communication → pre-power checks → power on & test. Follow the sections below in order.

## 2Bill of Materials

Qty | Item | Model / Spec | Role
1 | Motion controller | FMC4030 (3-axis) | Generates pulse/dir, reads limits, host comms
3 | Stepper driver | FMDD50D40NOM (DC20–50V, 1.0–4.0 A/phase) | One each: X-Left, X-Right, Y
3 | Stepper motor | 57HS056TF075A-03 (NEMA 23, 2-phase, 1.8°, 2.0 A, ≥80 N·cm) | X-Left rail, X-Right rail, Y cross-beam
4 | Limit / home switch | FSK40 photoelectric, NPN, normally-open (NO), 5–24 V | One pair on X-Left (+/−) and one pair on Y (+/−). X-Right has none.
1 | DC power supply | 24 VDC, sized for total load (≥ 3 × motor current + margin) | System power; AC 100–220 V input
1 | Ethernet cable | Standard RJ45 (to PC, router, or switch) | Host communication (CN3)
— | Wiring | Hook-up wire, ferrules, ground (PE) wire, cable, fuse/breaker on AC | Interconnect

Power supply sizing Each 57HS motor is rated 2.0 A. With three axes plus driver and controller overhead, choose a 24 V supply with comfortable headroom (a 24 V / 10 A unit is a safe starting point). The driver accepts DC 20–50 V, so 24 V is well within range.

## 3Safety & Tools

⚠ Electrical safety The power supply primary side carries 100–220 VAC. All wiring must be done with the system fully de-energized and the AC plug removed. Mains termination should be done by a qualified person. Never work on live terminals.

#### Do

- Wire everything with power OFF.
- Bond the controller PE terminal and the machine frame to protective earth.
- Double-check polarity (24V+ / 24V−) before powering up.
- Use ferrules on stranded wire entering screw terminals.
- Keep motor/driver power wiring separated from signal/Ethernet wiring.

#### Don't

- Don't plug/unplug the motor while the driver is powered — it can damage the driver.
- Don't exceed DC 50 V on the driver power input.
- Don't connect the motor connector with reversed coil pairs.
- Don't share the 5 V signal common with the 24 V power ground arbitrarily.

#### Tools

Small flat & Phillips screwdrivers, Allen/hex key set (for motor & flag mounts), wire stripper/crimper, ferrules, multimeter (continuity & voltage), and a PC with an Ethernet port.

## 4Component Specifications

### 4.1 Stepper motor — 57HS056TF075A-03

Phases | 2 | Step angle | 1.8° ±5%
Rated current | 2.0 A / phase | Rated voltage | 1.5 VDC
Resistance | 0.75 Ω ±10% | Inductance | 2.7 mH ±20%
Holding torque | ≥ 80 N·cm | Weight | 0.7 kg
Leads | 4-wire (XH-4 connector) | Frame | NEMA 23 (57 mm), Ø8 mm shaft

### 4.2 Stepper driver — FMDD50D40NOM

Type | 2-phase, DSP-based | Power input | DC 20–50 V
Drive current | 1.0–4.0 A/phase, 8 steps (SW1–SW3) | Microstep | up to 40000 steps/rev, 16 steps (SW5–SW8)
Max pulse rate | 200 Kpps | Pulse edge | Falling edge active
Idle current | Auto halves after pulses stop >1.5 s | Size / weight | 118 × 24.3 × 75.5 mm · 0.2 kg

### 4.3 Limit / home switch — FSK40 (NPN, NO)

Photoelectric switch, rated 5–24 V. NPN normally-open, low-level active — required by the FMC4030. When the flag blocks the beam, the switch triggers and the signal line is pulled to the active level.

Wire colour | Function | Connects to
Brown | +24 V supply | 24 V+ bus
Blue | 0 V (24 V−) | 24 V− bus
Black | Signal (NO) | Controller limit input (LP / LN)

On the FMC4030, these switches double as home/origin references. Per the FUYU limit-switch note, on a three-axis 4030 system the photoelectric switch provides the origin position for each axis (used by the zero-return / homing routine) in addition to acting as an end-of-travel limit. Install at least one per axis; install both ends for full positive/negative protection.

### 4.4 Controller — FMC4030

Controller power | 24 VDC (VN+/VN−) | Axis signal | 5 V pulse + direction, ×3
Limit inputs | 6 (LP/LN ×3), 24 V NPN-NO | Digital I/O | 4 in (24 V, low-active) · 4 out (24 V open-drain, ≤300 mA)
Comms | Ethernet (CN3), RS-232 DB9 (CN1), RS-232/485 RJ45 (CN2) | Default network | IP 192.168.0.30, port 8088

## 5Mechanical Assembly

Step 5.1 — Set up the gantry frame

Mount the two X rails parallel to each other and the Y cross-beam square (90°) across them. Gantry accuracy depends on this:

- Set the two X rails truly parallel and at the same height — measure the rail-to-rail distance at both ends and confirm it is equal.
- Mount the Y beam perpendicular to the rails; check the diagonals of the rectangle are equal to confirm square.
- Make sure both X carriages start at the same position along the rails before fixing the beam, so the gantry is square at its mechanical start.

Step 5.2 — Mount the motors

Bolt each 57HS motor to its actuator/axis motor mount using four M5 screws (NEMA 23 pattern, 47.14 mm): one on the X-Left rail, one on the X-Right rail, one on the Y beam. Make sure each motor shaft and lead-screw are concentric before tightening the coupling, and tighten the set-screws onto the shaft flats.

Mount both X motors the same way. Install the two X motors in the same orientation, on the same end of their rails (same-hand leadscrews). Then the same shaft rotation moves both carriages the same physical direction, so both motors get identical coil wiring and no reversal is needed (§8). (Only if a build mirror-mounts the two motors would one need its coils swapped — the §14 jog test would reveal it.)

Step 5.3 — Assign & label the axes

Label each motor cable and each driver. Both X drivers are fed from controller axis 1 (the shared X-gantry axis); the Y driver uses axis 3. Axis 2 is unused.

- X-Left driver/motor → controller axis 1 (5V/PU1/DR1)
- X-Right driver/motor → controller axis 1 (5V/PU1/DR1) — same terminals, paralleled
- Y driver/motor → controller axis 3 (5V/PU3/DR3)

Step 5.4 — Install limit-switch flags & sensors

The FSK40 photoelectric sensor mounts to the actuator carriage/rail; the red trigger flag mounts to the moving block so it passes through the sensor slot at each end of travel (see the FSK40 installation photo). With four switches, fit a + and − pair on X-Left and a + and − pair on Y — four total. X-Right gets none.

- Mount the sensor body so the moving flag enters the optical gap without mechanical contact.
- Position the positive-end sensor at the far/maximum-travel end, and the negative-end sensor at the home/zero end of each axis.
- Leave a few millimetres of margin before the hard mechanical stop so the switch trips before the carriage bottoms out.
- Confirm the indicator LED on the sensor changes state as the flag enters/leaves the slot.

Square the gantry mechanically. The X pair (on LP1/LN1, axis 1) becomes the home/limit for the whole gantry — homing axis 1 moves both motors together, so the gantry slides home as one unit with no fighting. But the controller can't move one rail relative to the other, so squareness comes entirely from the build (Step 5.1) and the rigid beam. Mount the X switch flags on one rail (e.g. X-Left). The opposite rail end has no over-travel switch, so set conservative soft-travel limits in software.

Step 5.5 — Mount controller, drivers & power supply

- Mount the FMC4030, the three drivers, and the 24 V supply in the control cabinet/panel.
- If drivers are mounted side-by-side, keep ≥ 50 mm between them for heat dissipation (they have thermal shutdown at 80 °C).
- Keep AC mains wiring physically separated from low-voltage signal wiring.

## 6Driver DIP Switch Setup

Set the DIP switches on each FMDD50D40NOM driver before wiring power. There are 8 switches: SW1–SW3 set current, SW4 sets mode, SW5–SW8 set microstepping.

SW4 must be OFF SW4 = OFF selects pulse/subdivision mode — this is required when driven by the FMC4030's PU/DR pulse signals. SW4 = ON puts the driver in I/O mode and the motor will not respond to pulses.

### 6.1 Output current (SW1–SW3)

Set the operating current to match the motor's rated 2.0 A. Peak = operating × 1.4.

Operating A | 1.0 | 1.2 | 1.5 | 2.0 ★ | 2.5 | 3.0 | 3.5 | 4.0
Peak A | 1.4 | 1.7 | 2.1 | 2.8 | 3.5 | 4.2 | 4.9 | 5.6
SW1 | ON | OFF | ON | OFF | ON | OFF | ON | OFF
SW2 | ON | ON | OFF | OFF | ON | ON | OFF | OFF
SW3 | ON | ON | ON | ON | OFF | OFF | OFF | OFF

★ Recommended for the 57HS motor (2.0 A): SW1 = OFF · SW2 = OFF · SW3 = ON

### 6.2 Microstepping (SW5–SW8, with SW4 = OFF)

Higher microstepping = smoother, quieter motion but more pulses per revolution (watch your max speed). A common general-purpose choice is 1600 steps/rev (8× microstep). Pick the same value on all three drivers and remember it — the software needs the steps/rev to compute distances.

Steps/rev | 200 | 400 | 800 | 1600 ★ | 3200 | 6400 | 12800 | 25600
SW5 | ON | OFF | ON | OFF | ON | OFF | ON | OFF
SW6 | ON | ON | OFF | OFF | ON | ON | OFF | OFF
SW7 | ON | ON | ON | ON | OFF | OFF | OFF | OFF
SW8 | ON | ON | ON | ON | ON | ON | ON | ON

A second bank of values (1000–40000 steps/rev) is available with SW8 = OFF; see the driver datasheet if you need those.

★ Suggested start (1600 steps/rev): SW5 = OFF · SW6 = OFF · SW7 = ON · SW8 = ON · (SW4 = OFF)

## 7Power Distribution Wiring

Build a simple 24 V bus from the supply and feed every device from it. Mains (100–220 VAC) goes only to the supply's L / N / earth terminals.

AC 100–220 V ──► [ 24 VDC SUPPLY ] ──► 24V+ bus ─┬─► Controller VN+ L N ⏚ 24V− bus ─┼─► Controller VN− ├─► Driver X-Left / X-Right / Y V+ , V− └─► All limit switches Brown(+24) , Blue(0V) Controller PE ──► machine frame ──► protective earth ⏚

From (24 V supply) | To | Wire
V+ (24 V+) | Controller VN+ | 24 V+
V− (24 V−) | Controller VN− | 24 V−
V+ (24 V+) | Each driver V+ | 24 V+
V− (24 V−) | Each driver V− | 24 V−
V+ (24 V+) | All limit switches Brown | 24 V+
V− (24 V−) | All limit switches Blue | 24 V−
Earth ⏚ | Controller PE + frame | PE

Check polarity before connecting anything else. With the supply on but no devices yet, meter the bus: it must read ≈ +24 V from 24V+ to 24V−. Then power off again before continuing.

## 8Motor → Driver Wiring

Each motor connects to its driver's A+/A−/B+/B− coil terminals. The 57HS motor's 4-pin (XH-4) connector colours map directly to the driver:

Motor pin | Motor colour | Coil | Driver terminal
1 | Black | A (A+) | A+
2 | Green | Ā (A−) | A−
3 | Red | B (B+) | B+
4 | Blue | B̄ (B−) | B−

Coil pairing is what matters. A = Black + Green, B = Red + Blue. If a motor runs rough, vibrates in place, or won't turn, you most likely split a coil pair — verify with a multimeter: the two wires of one coil show continuity (~0.75 Ω), across coils shows open.

Direction. Wire all three motors (X-Left, X-Right, Y) to their drivers using the colour map above. To flip a motor's direction, swap its A+ ↔ A− with power off. For the Y axis you can alternatively invert direction in software — but not for the X rails (they share one axis, so X direction is set only by wiring; see below).

Gantry direction: wire both X motors identically (same-orientation mounting). Both X drivers share one direction signal (axis 1), so both motors always rotate the same way at the same instant. Because both rails are mounted the same way (Step 5.2), that shared rotation moves both carriages the same physical direction — so use the standard coil colours (Black/Green/Red/Blue) on both motors. No A+/A− swap.

Why a swap is sometimes needed (not your case): if the two motors were instead mirror-mounted (one flipped 180°), the mirror would turn the same rotation into opposite travel and rack the gantry; you'd then swap A+ ↔ A− on one motor to cancel it. Since the DIR signal is shared, that correction can only be made in wiring, never in software.

Confirm with the §14 jog test: nudge axis 1 a few mm — both rails should move together in the same direction. If they move apart, one motor is effectively reversed (e.g. an opposite-hand screw or a flipped mount): power off and swap that motor's A+/A−.

## 9Driver → Controller Signal Wiring

Each driver takes three signals: a 5 V, a pulse (PU), and a direction (DR), in a common-anode connection — the controller's 5 V drives the driver's PU+ and DR+ (tied together), and the controller's pulse/direction pins sink into PU− and DR−. The key point for this gantry: the two X drivers are wired in parallel to the same controller axis (axis 1), so both receive identical pulses and step in lockstep. The Y driver uses axis 3. Axis 2 is unused.

FMC4030 axis 1 Both X drivers (paralleled) ────────────── ─────────────────────────── 5V ──┬──────────────────────────────► X-LEFT PU+ & DR+ └──────────────────────────────► X-RIGHT PU+ & DR+ PU1 ──┬──────────────────────────────► X-LEFT PU− └──────────────────────────────► X-RIGHT PU− DR1 ──┬──────────────────────────────► X-LEFT DR− └──────────────────────────────► X-RIGHT DR− (MF+/MF− on both: leave open) FMC4030 axis 3: 5V → PU+/DR+, PU3 → PU−, DR3 → DR− ──► Y driver

Driver | Controller axis | 5 V → | Pulse → | Dir →
X-Left | Axis 1 | 5V → PU+ & DR+ | PU1 → PU− | DR1 → DR−
X-Right | Axis 1 (same terminals) | 5V → PU+ & DR+ | PU1 → PU− | DR1 → DR−
Y | Axis 3 | 5V → PU+ & DR+ | PU3 → PU− | DR3 → DR−

Both X rows reference the same axis-1 terminals — you are landing two wires (one to each X driver) on each of 5V, PU1, DR1. Axis 2 (PU2/DR2) stays empty.

Why this gives perfect sync. With one pulse source feeding both X drivers, the controller physically cannot command the two rails differently — they step together by construction. No software interpolation or "move both axes equally" discipline is needed. The trade-off is that you cannot square the rails electronically (it's mechanical, §5.1) and X direction is fixed in wiring (§8).

Signal load: each driver input draws ~15–17 mA at 5 V; two in parallel (~35 mA) is well within the controller's drive capability. Keep the paralleled signal wires short / run them together. Note the 5 V only feeds the opto-isolator LEDs — it carries no motor current. Each driver makes its own motor current from its 24 V V+/V−.

Optional — split the 5 V across two terminals. The 5V pins on all three axes are the same internal 5 V rail, so if you'd rather distribute the anode load you may take X-Right's PU+/DR+ from the unused Axis-2 5V terminal instead of Axis-1 5V:

X-LEFT PU+/DR+ ← Axis-1 5V PU− ← PU1 DR− ← DR1 X-RIGHT PU+/DR+ ← Axis-2 5V PU− ← PU1 DR− ← DR1 ◄ signals STILL on axis 1

Only the 5 V tap moves — both drivers' PU−/DR− must stay on Axis 1's PU1/DR1, or you lose synchronisation. This is electrically unnecessary (two opto inputs total only ~34 mA, and it doesn't reduce the PU1/DR1 sink current) but harmless. Meter Axis-1 ↔ Axis-2 5V for continuity first to confirm they're the same rail.

Use the controller's 5 V — not 24 V — for PU+/DR+. Bridge axis 1's 5V terminal to both PU+ and DR+ on both X drivers. Do not feed 24 V into the driver's PU/DR inputs in this configuration.

MF (motor-free / enable): Leave MF+/MF− open on all drivers. When MF is energised (active-low) the driver releases the motor (no holding torque). You normally want holding torque, so leave it disconnected.

## 10Limit / Home Switch Wiring

Each FSK40 switch has three wires: Brown → 24 V+, Blue → 24 V−, Black → signal. The black signal wire goes to the matching limit input on the controller. Positive-end switches use LP inputs; negative-end switches use LN inputs.

FSK40 switch FMC4030 ──────────── ─────── Brown ──► 24 V+ bus Blue ──► 24 V− bus Black ──► LP1 / LN1 (X gantry, axis 1) · LP3 / LN3 (Y) — per table below

Axis | Positive-end switch (black →) | Negative-end switch (black →) | Signal ground
X gantry (axis 1) flags on one rail | LP1 (gantry X +) | LN1 (gantry X −, home) | GND — axis-1 limit ground (use for this pair)
Axis 2 | Unused. The X rails share axis 1, so axis 2 has no role — leave LP2 / LN2 unconnected. (You have 4 switches: the X pair here on axis 1, the Y pair on axis 3.)
Y (axis 3) | LP3 (Y +) | LN3 (Y −, home) | GND — axis-3 limit ground (use for this pair)

One ground per switch pair. Wire the X-Left pair's blue (0 V) and the controller-side return to the blue-tinted GND in the axis-1 group (next to LN1). Wire the Y pair to the purple-tinted GND in the axis-3 group (next to LN3). The three LimitGND terminals are internally common, so electrically any LimitGND works — but using the one in each pair's own group keeps the harness tidy and matches the colour code.

Must be NPN, normally-open (NO). The FMC4030 limit inputs are low-level active. A PNP switch will not read correctly. The brown/blue/black colour scheme above is for the FUYU FSK40 — verify against your switch's own label before connecting.

Polarity / direction sanity check: after power-on, manually slide each carriage toward an end and confirm the correct LP/LN input registers in the software's status panel. If "X+" trips when you move toward the X− end, swap that axis's LP and LN wires (power off first).

## 11Digital I/O & Communication (optional)

### 11.1 Digital inputs (IN0–IN3)

Four 24 V inputs, active low. Wire a switch/sensor signal to IN0…IN3 and its return to the input GND. Use for external start buttons, sensors, e-stop sense, etc.

### 11.2 Digital outputs (OP1–OP4)

Four 24 V open-drain outputs (sink ≤ 300 mA). Wire the load between 24 V+ and the output pin; the output pulls the load's low side to ground when active. Use for relays, valves, indicators, etc.

24V+ ──► [ Load / relay coil ] ──► OPx (FMC4030 sinks to GND when ON)

### 11.3 Host communication — Ethernet (CN3)

- Connect a standard RJ45 cable from the controller's CN3 to your PC, router, or switch.
- Controller defaults: IP 192.168.0.30, port 8088.
- Set the PC's network adapter to the same subnet, e.g. IP 192.168.0.35, mask 255.255.255.0, gateway 192.168.0.1.
- Verify with ping 192.168.0.30 -t. Replies = link is good.

Other ports (not needed for basic bring-up): CN1 = RS-232 DB9 (pin 2 TX, pin 3 RX) for touch screen/PC; CN2 = RJ45 carrying RS-232 debug and RS-485 (lines 4 & 5). Ethernet is the primary control link.

## 12Terminal Reference (Controller & Driver)

### 12.1 FMC4030 controller — every terminal in order

The controller has two terminal banks running along opposite edges of the board. Each bank is listed below in silkscreen order (left → right) with a short description on the outside, so each edge reads down its own column.

Each edge is independent. The two terminal columns are the two physical edges of the controller. Terminals sharing a row are not electrically related — the banks are simply shown side by side. The two banks also differ in length (14 vs 17 terminals).

Colour key: Axis 1 = both X drivers (gantry) X-Left limit Y Shared / power / I/O / unused

What it does ◄ | Signal / Output edge | Power / Limit / Input edge | ► What it does
5 V out → both X drivers (PU+ & DR+) | 5V | VN+ | 24 V controller power input (+)
Direction → both X drivers (gantry) | DR1 | VN− | 24 V controller power input (−)
Pulse / step → both X drivers (gantry) | PU1 | PE | Protective earth / chassis ground
Axis 2 5 V — unused | 5V | LP1 | Gantry X positive limit
Axis 2 direction — unused | DR2 | LN1 | Gantry X negative limit (home)
Axis 2 pulse — unused | PU2 | GND | Gantry X limit ground — use for the X pair
5 V out → Y driver (PU+ & DR+) | 5V | LP2 | Axis 2 limit — unused
Direction signal → Y | DR3 | LN2 | Axis 2 limit — unused
Pulse / step → Y | PU3 | GND | Axis 2 limit ground — unused
Digital output 4 (24 V open-drain) | OP4 | LP3 | Y positive limit
Digital output 3 | OP3 | LN3 | Y negative limit (home)
Digital output 2 | OP2 | GND | Y limit ground — use for the Y pair
Digital output 1 | OP1 | IN0 | Digital input 0 (24 V, active low)
Output common ground | GND | IN1 | Digital input 1
— (end of edge) | — | IN2 | Digital input 2
— | — | IN3 | Digital input 3
— | — | GND | Input common ground

### 12.2 FMDD50D40NOM driver — every terminal in order

Each driver carries control-signal terminals on one end and power/motor terminals on the other end, listed the same way: terminal label inside, short description outside. All three drivers (X-Left, X-Right, Y) are wired identically, so this table is not axis-coloured — it applies to each driver the same. The colours below are motor wire colours, not axis colours.

What it does ◄ | Control-signal end | Power / Motor end | ► What it does
Pulse opto-anode → tie to controller 5V | PU+ | V+ | DC power input + (20–50 V; 24 V here)
Pulse / step input → controller PUx (falling-edge active) | PU− | V− | DC power input − (0 V)
Direction opto-anode → tie to controller 5V | DR+ | A+ | Motor coil A+ — Black
Direction input → controller DRx | DR− | A− | Motor coil A− — Green
Enable opto-anode (leave open) | MF+ | B+ | Motor coil B+ — Red
Motor-free / enable — active releases the motor (leave open) | MF− | B− | Motor coil B− — Blue
24 V signal common — only for 24 V-signal mode (unused in this 5 V common-anode wiring) | COM24V (HSC) | — | — (end of edge)

## 13Pre-Power Checklist

Walk this list with the system still de-energized and a multimeter in hand.

- AC mains landed correctly on the supply L / N / earth; cover/strain-relief in place.
- 24 V bus polarity verified: +24 V from 24V+ to 24V− (no short to PE).
- Controller VN+/VN− correct; PE bonded to frame and earth.
- Each driver V+/V− correct polarity.
- Each motor coil pairs verified by continuity: A = Black+Green, B = Red+Blue.
- No motor connector to be plugged/unplugged with power on (connect now, while off).
- Both X drivers paralleled on axis 1: 5V → both PU+ & DR+; PU1 → both PU−; DR1 → both DR−. Y driver on axis 3 (5V/PU3/DR3). Axis 2 (PU2/DR2) empty.
- Both X motors wired identically (same-orientation mounting → no coil swap); direction confirmed by the §14 jog test.
- Limit switches (4): Brown→24V+, Blue→24V−, Black→correct input. Gantry X pair → LP1/LN1 + axis-1 GND; Y pair → LP3/LN3 + axis-3 GND. LP2/LN2 unconnected.
- Gantry squared mechanically at build (it cannot be squared electronically).
- Driver DIP set on all three: current = 2.0 A (SW1 OFF, SW2 OFF, SW3 ON), SW4 OFF, microstep chosen identically.
- Ethernet cable seated in CN3; PC NIC set to 192.168.0.x subnet.
- No loose strands, no terminals touching adjacent terminals, all screws tight.

## 14First Power-On & Bring-Up

1. Energize. Apply AC. Confirm the 24 V supply LED is on and the controller/driver power LEDs light. No driver should show a red ALM fault.
2. Network. From the PC run ping 192.168.0.30 -t and confirm replies.
3. Connect software. Launch the FUYU controller software, connect to 192.168.0.30 : 8088. (You must interact within ~1 minute or the controller drops idle clients — just reconnect if so.)
4. Check limit feedback. In the status panel, trip each fitted switch by hand and confirm the matching input toggles (gantry X → LP1/LN1 on axis 1, Y → LP3/LN3 on axis 3). Fix any swapped/active-state issues now.
5. Verify both X rails move together (do this first, tiny moves). Jog axis 1 a very small amount and watch both rails. They share the signal, so they move together — and with same-orientation mounting they should travel the same physical direction. If the carriages instead move apart (rack/bind), one motor is effectively reversed: power off and swap that motor's A+ ↔ A− (§8), then re-test. Don't make large moves until this is correct.
6. Jog the gantry (axis 1) and Y (axis 3) at low speed. Confirm:
  - Both X rails move smoothly together, square, no binding (rough motion → recheck coil pairing).
  - Y moves smoothly.
  - Each axis stops when its limit switch triggers.
7. Home the machine. Home axis 1 to LN1 — both X motors drive together, so the whole gantry slides home as one unit (no fighting). Home Y (axis 3) to LN3. Set this position as zero. Squareness comes from the mechanical build (Step 5.1), not from homing.

For the software phase: the gantry X is a single axis to the controller — in the SDK this is axis index 0 (terminals PU1/DR1); the Y beam is axis index 2 (PU3/DR3). One X command moves both rails in lockstep. No interpolation or "move both axes equally" logic is needed — that's the whole point of sharing the signal.

Hardware bring-up complete. With both X rails moving together squarely, Y jogging, homing working, and all four limits verified, the mechanical/electrical build is done. You're ready to move on to SDK/programming.

## 15Troubleshooting

Symptom | Likely cause | Fix
Motor vibrates / buzzes but won't rotate | Coil pair split between A and B | Verify pairing: A = Black+Green, B = Red+Blue (continuity test)
Motor does nothing on jog | SW4 in wrong mode, or PU/DR mis-wired | Set SW4 = OFF; check 5V→PU+/DR+, PUx→PU−, DRx→DR−
Axis runs the wrong direction | Direction polarity | X rails: swap one motor's A+/A− (wiring only). Y: swap A+/A− or invert in software
Gantry racks / binds the instant X moves | The two X rails travel opposite ways — one motor wired opposite, or an opposite-hand screw / flipped (mirror) mount | Confirm both X motors are wired identically; if one rail still runs opposite, power off and swap that motor's A+ ↔ A− (§8)
Gantry drifts out of square over time | A motor lost steps (stall/overload) — open-loop, no feedback | Reduce acceleration; raise current/torque margin; re-home (axis 1) after any fault
Gantry not square | Square depends on the mechanical build (can't square electronically) | Square the frame physically (§5.1); keep both X carriages locked to the rigid beam
Driver red ALM light on | Over-temp (>80 °C), over-current/short, or motor wiring fault | Power-cycle after cooling; check motor wiring/short; add spacing/heatsink
Limit never triggers / always triggered | Wrong switch type or LP/LN polarity | Must be NPN-NO; verify brown=24V+, blue=0V, black=signal; check correct input
"X+" trips when moving toward X− | LP/LN swapped | Swap that axis's LP and LN signal wires (power off)
No ping / can't connect | PC not on controller subnet | Set PC to 192.168.0.x / 255.255.255.0; cable in CN3
Connection drops after a minute | Idle timeout (by design) | Keep interacting, or just reconnect
Motor weak / overheating | Current set too low / too high | Set driver current to 2.0 A (SW1 OFF, SW2 OFF, SW3 ON)

## 16Control Software (FuyuRailController)

With the hardware wired and powered (§1–§14), the rails are driven from a small Qt desktop application — FuyuRailController — that talks to the FMC4030 over Ethernet. It reuses the lab's existing Velmex control panel (the same sliders, Calibrate / Center / Scan buttons and settings dialog) and only swaps the controller underneath to drive the FMC4030 instead of a serial Velmex VXM.

Scope. §1–§15 are assembly & wiring. This section is a short operator guide to the control app; full build / SDK details live in the project's FuyuRailController/README.md.

### 16.1 Connect

- Ethernet cable from the controller's CN3 to the PC (§11.3).
- Set the PC network adapter to the controller's subnet, e.g. 192.168.0.35 / 255.255.255.0.
- Controller default 192.168.0.30 : 8088; verify with ping 192.168.0.30 -t.
- Launch the app — a connection dialog appears first, with the controller's IP address and port (a Default button restores 192.168.0.30 : 8088).
- Click OK — the app tries to connect. On success it opens the control panel; on failure it shows the error and stays so you can correct the address/port. The working values are remembered for next time.

### 16.2 The control panel

The window stacks one group box per axis: X gantry (SDK axis 0 — both rails) and Y beam (SDK axis 2). Each axis is a 3-row grid of label · slider · value box · button:

┌─ X gantry Controls: ──────────────────────────────────────────┐ │[?] Left Limit: ●─────────────── [ 0.000 mm] [Calibrate]│ │ Slider Position: ────────●─────── [125.000 mm] [Center ]│ │ Right Limit: ───────────────● [250.000 mm] [Scan ]│ └──────────────────────────────────────────────────────────────────┘

Control | What it does
Left / Right Limit sliders | The soft travel limits. Normally set automatically by Calibrate; can be nudged by hand.
Slider Position | Commands an absolute move — drag the handle or type a value in the box. It is a setpoint (it jumps, it doesn't scroll).
Calibrate | Homes to the negative switch (sets zero), then seeks the positive switch (sets the travel). The slider range then reflects the real travel.
Center | Jumps the axis to the middle of its travel.
Scan | Stepped sweep from left to right in Scan Steps stops (placeholder hook for a camera-capture loop).
? (settings) | Units, Home Toward, Speed, Scan Steps — see §16.4.

### 16.3 First moves

1. Calibrate each axis first. It homes to the negative/home switch and seeks the positive switch, so the controller learns zero and the full travel from your limit switches (no travel is typed in by hand).
2. Then move: drag the Position slider, type a value, or press Center. The carriage drives there; the live position streams back.
3. Scan runs a stepped left→right sweep — wire its per-step signal to your capture routine when integrating with the recorder.

Gantry reminder. The two X rails are one controller axis (shared PU/DR), so "X gantry" moves both rails together — there is no way (and no need) to move one rail alone. Squareness comes from the mechanical build (§5.1).

### 16.4 Settings ( ? )

Field | Meaning
Units | millimeters (default) or inches. Switches the position readouts and the Speed field (mm/s ↔ in/s) on every axis.
Home Toward | Which end Calibrate homes to: toward the motor end (the +/LP switch) or away from the motor end (the −/LN home switch — the default).
Speed | Rail speed, 1–200 mm/s (shown in the selected unit).
Scan Steps | Number of stops in a Scan sweep.

### 16.5 Build & run

- Simulation (default): open FuyuRailController.pro in Qt Creator and Run — a built-in software simulator stands in for the controller, so the whole UI works with no hardware or SDK. Verified with Qt 6.9.3 / MSVC 2022 (64-bit).
- Real hardware: build with CONFIG+=hardware (Projects ▸ Build ▸ qmake additional arguments). The vendor FMC4030-Dll.dll already sits in FuyuRailController/sdk/ and is auto-copied next to the .exe by the project file — no manual copying.

Runtime-loaded DLL. The SDK library is loaded at run time (via QLibrary), so there is no link-time dependency — a hardware build launches even if the DLL is absent and simply reports disconnected. Use the 64-bit DLL with the 64-bit kit.

### 16.6 Blocking vs non-blocking SDK

FUYU ships two builds of FMC4030-Dll.dll — blocking and non-blocking — with identical function names but different behaviour. This project uses the non-blocking, 64-bit (X64) build, because the controller is poll-based: it issues one move command and then polls "is the axis stopped?" on a 500 ms timer.

| Non-blocking (used) | Blocking (do not use)
Motion call returns | immediately | only when the move finishes
Live position during a move | yes — the poll updates it | no — jumps at the end
Stop / abort mid-move | works | can't until the move ends
Controller thread during a move | responsive | frozen inside the call

Don't swap in the blocking DLL. With it the app still compiles, connects and completes simple moves — so it can look fine — but you lose live position feedback and the ability to abort a move, a safety concern on a gantry. If you re-extract the DLL, take it from the "non blocking" archive's X64 subfolder (see FuyuRailController/sdk/README.txt).

Under the hood. The app reuses the Velmex LAUVelmexWidget classes unchanged; only LAUVelmexController was reimplemented to drive the FMC4030 (Ethernet, native millimetres, non-blocking moves polled for completion). Internally 1 slider "count" = 1 µm.

FUYU FMC4030 Dual-X Gantry System — Assembly, Wiring & Software Manual · Rev 2.5
Rev 2.0: X rails wired in hardware lockstep — both X drivers share controller axis 1 (single shared PU/DR signal). Rev 2.1: optional 5 V split onto Axis-2 terminal; clarified why one X motor is reversed. Rev 2.2: same-orientation X mounting is the baseline — both X motors wired identically, no coil swap. Rev 2.3: added isometric layout figure (§1) with side-mounted limit switches. Rev 2.4: added §16 Control Software (FuyuRailController app). Rev 2.5: §16 updated — startup connection dialog, runtime-loaded DLL, and §16.6 blocking vs non-blocking SDK.
Compiled from FUYU OEM documentation (FMC4030 Controller User Manual V2001, FMDD50D40NOM driver guide, 57HS056TF075A-03 motor drawing, FSK40 limit-switch note, and the FMC4030-50D40 wiring diagram). Values such as current and microstep settings are starting recommendations — confirm against your specific machine and the latest FUYU documentation. Software/SDK setup is covered separately.

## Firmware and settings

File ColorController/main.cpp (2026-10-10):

#include <QApplication>
#include "laucolorprofilerwindow.h"

int main(int argc, char *argv[])
{
    QApplication a(argc, argv);

    // SHARE QSETTINGS WITH FuyuRailController SO THE GANTRY IP ADDRESS, CALIBRATION AND UNITS CARRY OVER
    a.setOrganizationName(QString("LAU"));
    a.setApplicationName(QString("FuyuRailController"));

    // THE GANTRY STARTS DISABLED; ITS CONNECT DIALOG APPEARS WHEN THE USER ENABLES IT IN THE WINDOW
    LAUColorProfilerWindow window;
    window.show();
    return (a.exec());
}

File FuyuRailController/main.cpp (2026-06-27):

/*********************************************************************************
 * Copyright (c) 2026, Dr. Daniel L. Lau -- All rights reserved.                 *
 *********************************************************************************/

#include <QApplication>
#include "lauvelmexwidget.h"

int main(int argc, char *argv[])
{
    QApplication application(argc, argv);

    // QSettings (used by the controller + widgets to persist limits / units / etc.)
    QCoreApplication::setOrganizationName(QString("LAU"));
    QCoreApplication::setApplicationName(QString("FuyuRailController"));

    // Let the user set the FMC4030 IP address / port (with a Test Connection button) before the
    // controller is created.  The dialog persists the values to QSettings, which the
    // LAUVelmexController reads on construction.  Cancel quits the application.
    LAUFuyuConnectDialog connectDialog;
    if (connectDialog.exec() != QDialog::Accepted) {
        return (0);
    }

    // The Velmex multi-axis widget, now driven by the FMC4030-backed LAUVelmexController.
    //   FMC4030 SDK axis 0 = X gantry (both rails share one controller axis)
    //   FMC4030 SDK axis 2 = Y cross-beam
    QList<int> axes;
    axes << 0 << 2;

    LAUMultiVelmexWidget widget(axes);
#ifdef FUYU_SIMULATE
    widget.setWindowTitle(QString("FUYU FMC4030 Rail Controller  —  SIMULATION (no hardware)"));
#else
    widget.setWindowTitle(QString("FUYU FMC4030 Rail Controller"));
#endif
    widget.show();

    return (application.exec());
}

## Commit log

2026-06-27 Initial commit: FMC4030 dual-X gantry manual, diagram, and controller
    - FUYU_FMC4030_Assembly_Wiring_Manual.html: assembly & wiring manual
    - gantry_iso.svg: isometric system diagram
    - FuyuRailController/: Qt/C++ controller app (runtime-loads FMC4030 SDK DLL)
2026-06-27 Expand README with full hardware and software documentation
    Cover system architecture, axis mapping, BOM, component specs, DIP-switch
    setup, wiring summary, mechanical/safety notes, and the FuyuRailController
    build/run, axis mapping, runtime behavior, and SDK requirements.
2026-06-27 Add rendered system diagram figure to README
    Rasterize gantry_iso.svg to docs/gantry_iso.png and embed it near the top
    of the README with a descriptive caption.
2026-08-12 Document FMC4030 network setup; find VS via vswhere in build check
    README: promote the two-line subnet note to its own "Network setup"
    section under "Building for real hardware". Covers identifying the
    cabled adapter, the 169.254.x.x APIPA symptom of an unconfigured port,
    the netsh command to set a static 192.168.0.35/24, and verification via
    ping plus Test-NetConnection on port 8088. Notes why the default gateway
    is left blank (it would compete with the internet adapter's default
    route), and that the app remembers the IP in QSettings, so the
    192.168.0.30 default only applies on a first run.
    _buildcheck.bat: the hardcoded vcvars64.bat path under
    "Visual Studio\2022\Community" no longer exis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
2026-09-28 Sync FuyuRailController from working copy: calibration, units, speed cap
    - Calibrate: approach each switch with ordinary moves (the SDK home
    times out after ~10 s), home to zero at the near switch, then drive
    to the far switch in chunked moves; log measured travel.
    - Home end is always the left/0 end of the sliders: flip the sign at
    the SDK boundary when homing toward the motor (positive) switch.
    - Cap every commanded speed (jog, scan, home) at 70 mm/s, including
    the settings-dialog range and the SDK call wrappers.
    - Add tools/fmc_set_scale.py to back up, set and verify the FMC4030
    per-axis subdivision/lead/soft limits (set to 1600 steps/rev and
    +/-650 mm to match the drivers' SW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
    [lauvelmexwidget.cpp, lauvelmexwidget.h, main.cpp]
2026-09-28 Re-enable Y axis; apply saved speed on connect and after scans
    - main.cpp: drive both X (SDK axis 0, PU1/DR1) and Y (SDK axis 2,
    PU3/DR3) again.
    - Push each axis's saved speed to the controller as soon as it
    connects; the controller otherwise starts every axis at 20 mm/s.
    - Scan cancel/finish now restore the saved speed instead of the
    hard-coded VELMEXDEFAULTVELOCITY, and the multi-axis reset addresses
    each widget's real axis rather than its list index.
    [lauvelmexwidget.cpp, main.cpp]
2026-09-30 Add FSK40 carriage adapter plate (CadQuery model, STL/STEP)
    65 x 48 x 10 mm plate flush with the FSK40 carriage top, with counterbored
    M4 x 12 SHCS holes on the carriage's 25 x 25 mm tapped pattern (offset 1 mm
    to match the carriage). fsk40_with_plate.py places it on the TraceParts FSK40
    model for a fit check; that output is gitignored since it embeds vendor geometry.
    [fsk40_carriage_plate.step, fsk40_carriage_plate.stl]
2026-09-30 README: FSK40 is the rail model, not the limit switch
    Add the FSK40 ball-screw modules to the BOM and describe the limit switches
    generically (slot-type photoelectric, NPN NO); their part number isn't recorded.
2026-09-30 Add carriage hinge plate and drop chain to the table
    carriage_chain.py: FSK40 carriage plate with a square-knuckle hinge on one long
    edge, and an identical 85 mm-pitch chain link, pinned with M4 x 55 SHCS (head
    recessed, nylock nut captive). The chain drapes from the cross-beam carriage
    onto the table: one link hangs, one slopes, one lies flat.
    hinged_plates.py: the two-plate hinge prototype the design came from.
    gantry_h.py / fsk40_with_chain.py: fit checks on the TraceParts FSK40 (outputs
    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
    [carriage_chain.step, carriage_hinge_plate.step, carriage_hinge_plate.stl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]
2026-10-01 Add print-in-place hinge plate/link, test coupon and folding chain
    - carriage_link_pip.py: carriage hinge plate + first link joined by a
    print-in-place hinge (45 deg cone pins in cone sockets, 0.4 mm clearance,
    0.5 mm knuckle face gap) instead of the M4 screw pin.
    - carriage_link_pip_test.py: just the hinge from that, cut down to a
    65 x 36 x 10 mm coupon for tuning the clearance.
    - folding_chain.py: plate + 5 links printed folded like an accordion,
    standing on edge (65 x 45 x 60 mm), diamond knuckles with the pin between
    the pages so each hinge folds flat; checks hinge range, folded clearance
    and the draped pose on the H-gantry.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
    [carriage_link_pip.step, carriage_link_pip.stl, carriage_link_pip_test.step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]
2026-10-01 Chain: long first link, windowed links, tight middle knuckles
    - First link off the carriage is twice the pitch (170 mm) so it reaches the
    table at an angle (~61 deg) instead of hanging straight down; exported as
    chain_link_long.stl/.step
    - Both links get a window through the leaf (10 mm wall, 6 mm corner radius)
    to save material: long 107 -> 47 cm3, standard 51 -> 30 cm3
    - Each link's middle knuckle now stops 0.2 mm short of the knuckles above it
    (was 2 mm) so links can't slide along the pin (LINK_CLEAR)
    [carriage_chain.step, chain_link.stl, chain_link_long.step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]
2026-10-05 Model the XY-H1 gantry on the 24x24 breadboard with the windowed chain
    fsk40_resize.py: builds the rails FUYU shipped (FSK40XY-H1, 310 x 610 mm
    work area per the 2026-05-27 quote) from the TraceParts FSK40-E1250 STEP.
    Base extrusion and ball screw are spliced in their plain middle, the guide
    rail is trimmed at the far end (25 mm hole pitch kept), the far end plate
    moves back and the carriage goes to mid-stroke. Writes fsk40_s310/s610.step
    and gantry_h1.step; h_gantry() is shared with the breadboard model.
    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
    [carriage_chain.step, carriage_hinge_plate.step, carriage_hinge_plate.stl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]
2026-10-05 Add 80/20 push cart for the breadboard gantry, with hardware and BOM
    gantry_cart.py: cart under the 24 x 24 breadboard. 1010 top frame centred
    on the board's outermost hole rows/columns (flush outside), 2020 legs,
    2323 5 in braked swivel casters on 2419 plates, electronics shelf just
    below the top frame (clears a driver on edge), and a 14 in laptop table
    cantilevered off the leg-rail motor end on the extended 1010 top rails.
    Panels are 2633 Lite ACM. Profiles are cut to length from 80/20 stock
    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
    [cart_bom.csv]
2026-10-05 Cart: overhead camera mast, bracket fixes, 2-screw caster plates
    Camera mast: 1010 upright at the +X end (opposite the laptop table),
    held to the top and shelf right rails by four 4132s; a 13 in 1010 boom
    slides on it (one 4132 above, one below) and carries a USB camera on a
    ball head looking down at the board centre. CAMERA_HEIGHT (36 in max,
    ~7 in min to clear the gantry) sets the mast length: 45.71 in, cart
    70.4 in tall so it clears an 80 in door.
    Hardware fixes from collision checks:
    - 4132 modelled with edge ribs, 0.125 in flanges, holes 0.5 in out;
    bracket screws are 1/4-20 x 3/8 (a 1/2 in screw bottoms out in the
    0.323 in deep 1010 slot). All 28 joints check clean.
    - Mast-side T-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
    [cart_bom.csv]
2026-10-05 Add X-Rite i1 cradle plate hinged to the end of the carriage chain
    xRitei1.stl is the SketchUp cradle (ring around the i1 aperture, triangle
    frame, pocket). xrite_i1_plate.py rebuilds it exactly from its layer outlines,
    adds a 5 mm bar across the pocket end (its end wall was 1.3 mm) and the chain's
    middle knuckle (5.0 mm pivot, LINK_CLEAR side clearance), so it pins to the last
    link and lies flat on the table with the aperture floor down.
    carriage_chain.py: hanging_chain() takes optional link angles; chain_end()
    gives the last pin's position. gantry_on_plate.py now ends the chain in the
    i1 plate, flat on the breadboard.
    [carriage_chain_xrite.step, xRitei1.stl, xrite_i1_plate.step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]
2026-10-05 Update i1 cradle from revised SketchUp model (lower ring, ramped arms)
    The new xRitei1.stl lowers the ring to 6.76 mm and ramps the arms up to a
    10.76 mm pocket end, so it is no longer flat layers: xrite_i1_plate.py now
    sews the mesh triangles into a solid (dropping SketchUp's zero-area slivers),
    and the hinge bar is full cradle height.
    [xRitei1.stl, xrite_i1_plate.step, xrite_i1_plate.stl]
2026-10-05 Chain hinge pin: M4 x 60 Phillips pan head instead of M4 x 55 SHCS
    End knuckles get an 8.4 mm x 4 mm head counterbore (pan head 8.0 x 3.1) and
    a 7 mm nylock pocket, so the 60 mm screw runs from x = 4 to 64: 1 mm through
    the nut, 1 mm inside the end face. hinge_half() takes an optional pivot_d.
    [carriage_chain.step, carriage_chain_xrite.step, carriage_hinge_plate.step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]
2026-10-05 Add knuckle print-test coupon with 4.5 and 4.0 mm pivot holes
    Chain end knuckles on a short leaf plus two middle-knuckle pieces with the
    pivot hole reduced from 5.0 mm by 0.5 and 1.0 mm (engraved on top), to test
    the inner-knuckle wiggle. knuckle_test_plate.stl has all three side by side.
    [knuckle_test_inner_4.0.stl, knuckle_test_inner_4.5.stl, knuckle_test_outer.stl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]
2026-10-05 Chain: model M4 screws and nuts, add knuckle test coupon
    - carriage_chain.py: replace the plain pins with an M4 socket head screw
    (hex socket) and a nylock nut in its pocket; hinge_half takes pivot_d
    - fsk40_with_chain.py / gantry_h.py: show screws and nuts; gantry_h gets
    --xray to make the plate and links see-through
    - knuckle_test.py: one outer and one inner knuckle to print and test the
    pivot hole fit, with the hole size engraved on the inner piece
    [carriage_chain.step, carriage_hinge_plate.step, chain_link.step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]
2026-10-05 Chain: 4.0 mm hinge holes, single long link, combined print plate
    - PIN_D and PIVOT_D both 4.0 mm (4.0 won the knuckle test over 4.5);
    every hinge (carriage plate, long link, i1 plate) picks it up
    - N_LINKS = 1: carriage plate -> long link -> X-Rite i1 plate. Drop
    the short chain_link STL/STEP; link_pitches(n) now returns n pitches
    - xrite_i1_plate.py also writes chain_print_plate.stl: carriage plate,
    long link and i1 plate flat side by side (210 x 180 mm) for one print
    - knuckle_test.py: fixed 4.5 / 4.0 test holes instead of offsets from
    PIVOT_D
    [carriage_chain.step, carriage_chain_xrite.step, carriage_hinge_plate.step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]
2026-10-05 i1 plate: raise hinge pivot, fix pin screw/nut, lengthen bar to 15 mm
    - Pivot axis now PIVOT_Z = SWING_CLEAR (8.07 mm) above the underside instead of
    T/2, so the long link's square end knuckles stay 1 mm clear of the table at any
    angle; the knuckle is filled down to the underside so it still prints flat.
    - Plate pin screw and nut sit on the plate's pin axis and tilt with the last
    link (head and nut are in its end knuckles).
    - BAR 5 -> 15 mm: cradle 10 mm further from the hinge so the link clears the i1.
    [carriage_chain_xrite.step, chain_print_plate.stl, xrite_i1_plate.step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]
2026-10-06 Cart: split into bench box + wheeled cart, add quote and purchase request
    - gantry_cart.py: the stand is now two parts. Bench box = 24 x 24 1010 top
    frame, short 2020 posts and the electronics shelf, flush underneath so it
    sits on a workbench; it keeps the camera mast. Wheeled cart = 2020 legs on
    the 2323/2419 casters, a 1010 top frame whose X rails cantilever 14 in to
    carry the laptop table at cart-top height, a lower 1010 ring, and four
    2 x 2 x 1/8 corner angles that locate the box. Board top stays at 30 in.
    Shelf and ring rails use 4132s on their inner faces so nothing protrudes.
    Also writes wheeled_cart.step (git-ignored).
    - cart_bom.py: lines tagged by unit, parts and pric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
    [cart_bom.csv, gantry_stand_purchase_request.xlsx]
2026-10-10 Add ColorController (i1Pro + ArgyllCMS) and carriage camera mast + Basler bracket
    ColorController: new Qt app ported from LAUXRiteController (i1Pro path only)
    - LAUColorChart/LAUColorPatch: patch model and Argyll .ti1/.ti2/.ti3 I/O
    (.ti3 carries XYZ + 36-band spectra; verified with colprof 1.6.3, CMYK and iRGB)
    - LAUArgyllRunner: targen/colprof as separate processes (no AGPL linking)
    - LAUi1ProDevice: headless i1Pro SDK wrapper (spot + scan with correlation)
    - LAUChartLayout: scan-line chart sized to the gantry area per X-Rite's i1Pro
    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
    [camera_mount.step, camera_mount.stl, camera_mount_assembly.step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]
2026-10-12 Add vision prototype: platen hole-grid calibration and scan mosaic
    Python/OpenCV prototype for scanning the platen with the carriage camera:
    - render_scan.py: synthetic camera frames of the platen (optional paper target)
    - holegrid.py: hole detection, lattice fit and absolute hole indexing
    - scan_map.py: camera + carriage-axis calibration from a bare-platen scan,
    carriage mask and flat-field
    - mosaic.py: platen mosaic from a second pass at the same carriage positions
    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
2026-10-13 Vision: swatch centres, i1 aperture calibration, VTK renderer
    - target.py: swatch centres from the platen mosaic without registration
    marks. Fits the paper edges, then the swatch block's edges inside the
    sheet, and places every swatch from the chart layout (rows, cols, gap).
    Simulated 32 x 43 sheet of 6 mm swatches: centres within 0.29 mm, 0.01 mm
    relative to each other.
    - aperture.py: the i1 aperture's platen position at home (A0) from frames
    of the black plate over white paper, corrected for the plate floor
    hiding part of the disc; rail_for() turns a platen point into a rail
    move. Simulated end to end: the aperture lands within 0.02 mm of every
    swatch centre (the camera cal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
2026-10-13 Vision: plumb-line lens distortion calibration
    plumbline.py fits radial distortion (k1, k2) so that every row, column and
    diagonal of detected holes is straight once undistorted. It uses only which
    holes share a line, not the hole spacing, camera pose or carriage position,
    so it is an independent check on (or starting point for) the joint
    calibration in scan_map.py. On the simulated 15-frame bare scan it
    straightens 569 lines from 1.30 px to 0.039 px RMS and matches the true
    lens to within 0.07 px across the image.
    Also corrects the simulated lens's corner distortion note (~37 px).
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2026-10-22 Stand: 4166 locator plates, master BOM with 80/20 machining and screw check
    - Locators: 6 x 4166 6-hole flat plates (two per mast-side corner, one per
    laptop-side corner) replace the 2 x 2 x 1/8 aluminium angles; 22 x 3393.
    - cart_bom.py is now the single master BOM: every line an 80/20 part or
    machining service (7064 end taps on the leg bottoms for the 2419, 7599
    corner notches on the shelf), 2650 solid-core ACM panels, 3393 (1/2 in)
    bracket bolts instead of the too-short 3416, 3110/3064 caster screws.
    Prints a head-type + length check for every joint; parts 80/20 doesn't
    sell are listed for approval and kept out of the total.
    - 3321 is a flanged button head: drop the "countersi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
2026-10-30 BOM: gantry M4 fixings and their positions
    cart_bom.py lists the 6 x M4 x 20 SHCS + nuts that fix the gantry legs to
    the breadboard (needs approval, not 80/20, not in the total), with their
    positions from gantry_on_plate.py: outermost hole rows, 8.5 / 15.5 / 22.5 in
    from the motor-end edge. Adds them to the screw check (tip and nut inside
    the A rail's top slot). The assembly guide's mounting step gives the
    positions and the legs' ~5/8 in overhang past the mast-side edge.
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2026-11-06 Vision on real camera frames; BreadboardCalibration Qt app
    holegrid.py, made to work on the real Basler frames:
    - Grid fit is a homography plus radial lens distortion (k1, k2), fitted
    robustly. The real lens bows hole rows by ~110 px at the corners, which
    made the plain homography reject correct holes.
    - Shape check compares each hole with its lattice neighbours (real holes
    are cylinders seen down their walls off-axis, not flat discs).
    - Tapped holes under a low light: thread highlights and the lit hole wall
    count as part of the hole; the rim is searched from the outside in.
    - Background estimated at 1/4 scale (about 3x faster).
    New Python tools: live_clahe.py (simple live view: Mon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
2026-11-09 Add GantryController: camera and rails in one window, live calibration
    New GantryController app with the camera above the rail sliders. Choosing
    Calibrate moves the rails home (X mid-travel, Y 5 mm short of the idler
    switch) behind an abortable progress dialog, then opens a live dialog that
    recalibrates on each new frame until the user locks one in. The main window
    then shows live video with the lens distortion removed.
    LAUImageView is now a QOpenGLWidget: levelling and lens correction run in
    fragment shaders from raw Mono10 frames. The camera UI moves to right-click
    menus and builds without the pylon SDK (ENABLEPYLON).
    Update comments and docs for the as-built axes: single rail = X (axis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
2026-11-09 GantryController: platen scan, three-item live video menu
    Calibrate platen and Scan platen drive the rails through a 7 x 5 grid,
    settle at each stop, and save averaged 8-bit frames with a scan.json that
    vision/scan_map.py and mosaic.py read. Exposure is locked during a scan,
    the rail pair only steps between rows, and a scan can be aborted.
    The main live video now only shows live pictures, raw until the camera is
    calibrated and lens corrected after. The calibration views live solely in
    the Live Calibration dialog, which the standalone app now uses too. The
    main menu has no icon column.
2026-11-09 GantryController: merge platen scans in C++, live guides, inspection
    Scan positions now come from the calibrated view and the rail travel, the
    lens calibration is kept in QSettings, and the rails return home after a
    completed scan.
    LAUPlatenMosaic ports scan_map, mosaic, label_mosaic and hole_sliders to
    C++, merging about 65x faster than the Python on the recorded scan with
    matching hole maps. The cradle mask is now a fixed outline in camera rays.
    The merged image opens in an inspection dialog with wheel zoom, momentum
    drag and export. The live view gets the same controls and frame export,
    and draws the holes, platen edges and i1 reach from the rails' position,
    predicted between the contro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
2026-11-09 ColorController: open the i1 Pro directly over USB
    LAUi1ProUsb talks to a gray i1 Pro through libusb-win32, with neither
    the X-Rite SDK nor ArgyllCMS. The instrument hangs on GET_STATUS under
    WinUSB and libusbK, so it needs that driver. This first step opens the
    device and makes vendor reads; firmware 502 reads back correctly.
    Not yet part of a build.
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2026-11-10 GantryController: find printed targets on the platen scan
    LAUTargetFinder ports vision/target.py to C++ (find), matching the
    Python to 0.02 mm on the synthetic charts. findPrint locates targets
    from Generate print target: the paper's edges give the sheet, then the
    patch block is matched by its expected look in four orientations and
    pinned by local matches, so white patches, printed labels and where the
    printer put the page don't matter.
    Generated targets now also carry printtarg's .cht in their XMP, with
    the quarter turn and page size; LAUPrintTarget reads a target back from
    the TIFF alone. On synthetic scans of real printtarg pages, patch
    centres land within 0.1 mm; a wrong target is refus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
2026-11-10 GantryController: save each merge's platen geometry, share the rail conversion
    Every merge now writes mosaic/platen_mosaic.json: the transform from a
    platen_mosaic.png pixel to board mm (undoing the crop, flips and
    transpose) and the rail model (A0, ex, ey, travel). LAUPlatenGeometry
    loads it, maps picture points to board mm and back, and holds the one
    copy of the board-to-rails conversion, which the merge now uses for
    hole_sliders.csv.
    Merging the same scan with the old and new code gives byte-identical
    outputs, including hole_sliders.csv; the saved transform puts all 608
    confirmed holes on their dark centres (RMS 0.18 mm).
2026-11-10 GantryController: Scan target measures a printed target with the i1 Pro
    Scan target replaces Scan platen. It asks for the target TIFF first,
    has the camera scan and merge the platen, then finds every patch
    (findPrint), shows them for confirmation and turns each into rail
    positions. After a warning it switches to the i1 Pro: calibration on
    its white tile, then a live camera check that the i1 is seated in its
    cradle (the platen calibration's carriage mask, compared with the
    empty cradle; an override is offered). The rails then stop on each
    patch, one page strip at a time, for an i1 reading in its own thread.
    Readings go to a spectral .ti3 after every patch, and spec2cie adds XYZ
    at the end for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
2026-11-11 docs: plan a dry run through the empty i1 holder
    Check five patch crossings through the holder's hole before measuring, fit a
    correction to the patch positions, and refine the aperture calibration.
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2026-11-11 GantryController: fine-tune page corners with the i1 hole
    New right-click action "Fine-tune page corners...": the sliders put the i1
    holder's hole over each corner of the page found by the newest scan. A
    non-modal dialog nudges the rails so the paper moves up/down/left/right in
    the live picture (step 0.1-2 mm), and Centered confirms each corner before
    the next. The confirmed rail positions give a correction (affine for 3-4
    corners, similarity for 2, offset for 1) that is saved, after a summary, in
    the scan's platen_mosaic.json (rails.fix_single_pair, applied by
    LAUPlatenGeometry::railsFor) along with corner_tune.json.
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2026-11-11 GantryController: corners at the edge of the travel, print under the hole
    - Every page corner is visited: the sliders go as close as their travel
    allows. A corner they can't bring under the hole is reported as out of
    reach with Next corner / Cancel; if the camera still saw it through the
    hole it counts toward the correction.
    - findHole takes the convex outline of the paper it sees, so print under
    the hole is caught by the brightness check instead of biasing the centre
    (the bottom-right hole was off 2.3 mm by a logo); a rejected spot is
    retried 20 and 30 mm in from the corner.
    - Centred means within 0.1 mm (about what the rails repeat to), at most
    4 moves.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
2026-11-11 GantryController: fine-tune uses the limit sliders' full range
    The scan's saved travel keeps 5 mm clear of the end switches, which left
    page corners at the edge of the platen out of reach. Fine-tuning now
    moves anywhere between the limit sliders as they are set (new
    LAUMultiVelmexWidget::limitRange); the scan's own travel is put back
    before the correction is saved.
2026-11-11 GantryController: page coordinates to slider positions
    Saving a page-corner fine-tune now also writes page_sliders.json: a
    perspective map from the page's own mm (origin at its top-left corner as
    the merged picture shows it, X toward the top-right corner, Y toward the
    bottom-left) to slider positions, through the four corners' centred
    positions (the corrected model's for any corner not centred), so it is
    exact at every centred corner.
    New right-click action Go to page position... asks for X and Y on the
    newest fine-tuned page and moves the i1's hole there.
